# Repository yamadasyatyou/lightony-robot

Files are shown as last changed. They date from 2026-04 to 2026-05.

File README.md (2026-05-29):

# LIGHTONY ROBOT
lightony_robot_readme

A Spresense-based lamp robot with voice recognition.

---

## Overview
LIGHTONY is an interactive lamp robot powered by the Sony Spresense platform. It features voice recognition capabilities, allowing it to respond to voice commands and express emotions through light and movement.

🏆 **Winner of the Grand Prize (Entertainment Category) at [the SPRESENSE Application Contest 2025](https://elchika.com/promotion/spresense2025/winner/#nav)**

🎥 **Watch the demo video:** [Click here to watch on YouTube](https://youtube.com/shorts/HmzlsDdo05Y?si=zyfIlw46z9iSeXyk)

## Features
* **Voice Recognition:** Understands and reacts to specific voice commands.
* **Interactive Lighting:** Expresses different states and emotions using LEDs.
* **Spresense Powered:** Utilizes the high-performance computing of the Sony Spresense board.

## Directory Structure
```text
lightony-robot/
 ├── hardware/      # Mechanical and PCB design files (with schematics)
 ├── software/      # Source code for Sony Spresense
 └── README.md
```
## Acknowledgments
The edge AI implementation and Spresense control in this project were greatly inspired by and developed with reference to the following book and its accompanying repository:

* **Book:** *[SPRESENSEではじめるローパワーエッジAI](https://www.oreilly.co.jp/books/9784873119670/)* (Low-Power Edge AI with SPRESENSE) by Yoshinori Oota
* **Repository:** [TE-YoshinoriOota/Spresense-LowPower-EdgeAI](https://github.com/TE-YoshinoriOota/Spresense-LowPower-EdgeAI)

## License
This project is dual-licensed to protect both the software and the hardware designs:

* **Software (Source Code):** Licensed under the [GNU Lesser General Public License v2.1 (LGPL-2.1)](LICENSE).
* **Hardware & 3D Models:** Licensed under the [Creative Commons Attribution-NonCommercial 4.0 International (CC BY-NC 4.0)](https://creativecommons.org/licenses/by-nc/4.0/). 
  *(Non-commercial use only. Selling the physical robot or parts is strictly prohibited.)*

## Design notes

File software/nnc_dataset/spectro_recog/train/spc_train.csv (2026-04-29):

x:scp | y:label
./wake_up/000.bmp | 0
./wake_up/001.bmp | 0
./wake_up/002.bmp | 0
./wake_up/003.bmp | 0
./wake_up/004.bmp | 0
./wake_up/005.bmp | 0
./wake_up/006.bmp | 0
./wake_up/007.bmp | 0
./wake_up/008.bmp | 0
./wake_up/009.bmp | 0
./wake_up/010.bmp | 0
./wake_up/011.bmp | 0
./wake_up/012.bmp | 0
./wake_up/013.bmp | 0
./wake_up/014.bmp | 0
./wake_up/015.bmp | 0
./wake_up/016.bmp | 0
./wake_up/017.bmp | 0
./wake_up/018.bmp | 0
./wake_up/019.bmp | 0
./wake_up/020.bmp | 0
./wake_up/021.bmp | 0
./wake_up/022.bmp | 0
./wake_up/023.bmp | 0
./wake_up/024.bmp | 0
./wake_up/025.bmp | 0
./wake_up/026.bmp | 0
./wake_up/027.bmp | 0
./wake_up/028.bmp | 0
./wake_up/029.bmp | 0
./wake_up/030.bmp | 0
./wake_up/031.bmp | 0
./wake_up/032.bmp | 0
./wake_up/033.bmp | 0
./wake_up/034.bmp | 0
./wake_up/035.bmp | 0
./wake_up/036.bmp | 0
./wake_up/037.bmp | 0
./wake_up/038.bmp | 0
./wake_up/039.bmp | 0
./wake_up/040.bmp | 0
./wake_up/041.bmp | 0
./wake_up/042.bmp | 0
./wake_up/043.bmp | 0
./wake_up/044.bmp | 0
./wake_up/045.bmp | 0
./wake_up/046.bmp | 0
./wake_up/047.bmp | 0
./wake_up/048.bmp | 0
./wake_up/049.bmp | 0
./good_night/000.bmp | 1
./good_night/001.bmp | 1
./good_night/002.bmp | 1
./good_night/003.bmp | 1
./good_night/004.bmp | 1
./good_night/005.bmp | 1
./good_night/006.bmp | 1
./good_night/007.bmp | 1
./good_night/008.bmp | 1
./good_night/009.bmp | 1
./good_night/010.bmp | 1
./good_night/011.bmp | 1
./good_night/012.bmp | 1
./good_night/013.bmp | 1
./good_night/014.bmp | 1
./good_night/015.bmp | 1
./good_night/016.bmp | 1
./good_night/017.bmp | 1
./good_night/018.bmp | 1
./good_night/019.bmp | 1
./good_night/020.bmp | 1
./good_night/021.bmp | 1
./good_night/022.bmp | 1
./good_night/023.bmp | 1
./good_night/024.bmp | 1
./good_night/025.bmp | 1
./good_night/026.bmp | 1
./good_night/027.bmp | 1
./good_night/028.bmp | 1
./good_night/029.bmp | 1
./good_night/030.bmp | 1
./good_night/031.bmp | 1
./good_night/032.bmp | 1
./good_night/033.bmp | 1
./good_night/034.bmp | 1
./good_night/035.bmp | 1
./good_night/036.bmp | 1
./good_night/037.bmp | 1
./good_night/038.bmp | 1
./good_night/039.bmp | 1
./good_night/040.bmp | 1
./good_night/041.bmp | 1
./good_night/042.bmp | 1
./good_night/043.bmp | 1
./good_night/044.bmp | 1
./good_night/045.bmp | 1
./good_night/046.bmp | 1
./good_night/047.bmp | 1
./good_night/048.bmp | 1
./good_night/049.bmp | 1
./brightly/000.bmp | 2
./brightly/001.bmp | 2
./brightly/002.bmp | 2
./brightly/003.bmp | 2
./brightly/004.bmp | 2
./brightly/005.bmp | 2
./brightly/006.bmp | 2
./brightly/007.bmp | 2
./brightly/008.bmp | 2
./brightly/009.bmp | 2
./brightly/010.bmp | 2
./brightly/011.bmp | 2
./brightly/012.bmp | 2
./brightly/013.bmp | 2
./brightly/014.bmp | 2
./brightly/015.bmp | 2
./brightly/016.bmp | 2
./brightly/017.bmp | 2
./brightly/018.bmp | 2
./brightly/019.bmp | 2
./brightly/020.bmp | 2
./brightly/021.bmp | 2
./brightly/022.bmp | 2
./brightly/023.bmp | 2
./brightly/024.bmp | 2
./brightly/025.bmp | 2
./brightly/026.bmp | 2
./brightly/027.bmp | 2
./brightly/028.bmp | 2
./brightly/029.bmp | 2
./brightly/030.bmp | 2
./brightly/031.bmp | 2
./brightly/032.bmp | 2
./brightly/033.bmp | 2
./brightly/034.bmp | 2
./brightly/035.bmp | 2
./brightly/036.bmp | 2
./brightly/037.bmp | 2
./brightly/038.bmp | 2
./brightly/039.bmp | 2
./brightly/040.bmp | 2
./brightly/041.bmp | 2
./brightly/042.bmp | 2
./brightly/043.bmp | 2
./brightly/044.bmp | 2
./brightly/045.bmp | 2
./brightly/046.bmp | 2
./brightly/047.bmp | 2
./brightly/048.bmp | 2
./brightly/049.bmp | 2
./darkly/000.bmp | 3
./darkly/001.bmp | 3
./darkly/002.bmp | 3
./darkly/003.bmp | 3
./darkly/004.bmp | 3
./darkly/005.bmp | 3
./darkly/006.bmp | 3
./darkly/007.bmp | 3
./darkly/008.bmp | 3
./darkly/009.bmp | 3
./darkly/010.bmp | 3
./darkly/011.bmp | 3
./darkly/012.bmp | 3
./darkly/013.bmp | 3
./darkly/014.bmp | 3
./darkly/015.bmp | 3
./darkly/016.bmp | 3
./darkly/017.bmp | 3
./darkly/018.bmp | 3
./darkly/019.bmp | 3
./darkly/020.bmp | 3
./darkly/021.bmp | 3
./darkly/022.bmp | 3
./darkly/023.bmp | 3
./darkly/024.bmp | 3
./darkly/025.bmp | 3
./darkly/026.bmp | 3
./darkly/027.bmp | 3
./darkly/028.bmp | 3
./darkly/029.bmp | 3
./darkly/030.bmp | 3
./darkly/031.bmp | 3
./darkly/032.bmp | 3
./darkly/033.bmp | 3
./darkly/034.bmp | 3
./darkly/035.bmp | 3
./darkly/036.bmp | 3
./darkly/037.bmp | 3
./darkly/038.bmp | 3
./darkly/039.bmp | 3
./darkly/040.bmp | 3
./darkly/041.bmp | 3
./darkly/042.bmp | 3
./darkly/043.bmp | 3
./darkly/044.bmp | 3
./darkly/045.bmp | 3
./darkly/046.bmp | 3
./darkly/047.bmp | 3
./darkly/048.bmp | 3
./darkly/049.bmp | 3
./clap/000.bmp | 4
./clap/001.bmp | 4
./clap/002.bmp | 4
./clap/003.bmp | 4
./clap/004.bmp | 4
./clap/005.bmp | 4
./clap/006.bmp | 4
./clap/007.bmp | 4
./clap/008.bmp | 4
./clap/009.bmp | 4
./clap/010.bmp | 4
./clap/011.bmp | 4
./clap/012.bmp | 4
./clap/013.bmp | 4
./clap/014.bmp | 4
./clap/015.bmp | 4
./clap/016.bmp | 4
./clap/017.bmp | 4
./clap/018.bmp | 4
./clap/019.bmp | 4
./clap/020.bmp | 4
./clap/021.bmp | 4
./clap/022.bmp | 4
./clap/023.bmp | 4
./clap/024.bmp | 4
./clap/025.bmp | 4
./clap/026.bmp | 4
./clap/027.bmp | 4
./clap/028.bmp | 4
./clap/029.bmp | 4
./clap/030.bmp | 4
./clap/031.bmp | 4
./clap/032.bmp | 4
./clap/033.bmp | 4
./clap/034.bmp | 4
./clap/035.bmp | 4
./clap/036.bmp | 4
./clap/037.bmp | 4
./clap/038.bmp | 4
./clap/039.bmp | 4
./clap/040.bmp | 4
./clap/041.bmp | 4
./clap/042.bmp | 4
./clap/043.bmp | 4
./clap/044.bmp | 4
./clap/045.bmp | 4
./clap/046.bmp | 4
./clap/047.bmp | 4
./clap/048.bmp | 4
./clap/049.bmp | 4
./blow/000.bmp | 5
./blow/001.bmp | 5
./blow/002.bmp | 5
./blow/003.bmp | 5
./blow/004.bmp | 5
./blow/005.bmp | 5
./blow/006.bmp | 5
./blow/007.bmp | 5
./blow/008.bmp | 5
./blow/009.bmp | 5
./blow/010.bmp | 5
./blow/011.bmp | 5
./blow/012.bmp | 5
./blow/013.bmp | 5
./blow/014.bmp | 5
./blow/015.bmp | 5
./blow/016.bmp | 5
./blow/017.bmp | 5
./blow/018.bmp | 5
./blow/019.bmp | 5
./blow/020.bmp | 5
./blow/021.bmp | 5
./blow/022.bmp | 5
./blow/023.bmp | 5
./blow/024.bmp | 5
./blow/025.bmp | 5
./blow/026.bmp | 5
./blow/027.bmp | 5
./blow/028.bmp | 5
./blow/029.bmp | 5
./blow/030.bmp | 5
./blow/031.bmp | 5
./blow/032.bmp | 5
./blow/033.bmp | 5
./blow/034.bmp | 5
./blow/035.bmp | 5
./blow/036.bmp | 5
./blow/037.bmp | 5
./blow/038.bmp | 5
./blow/039.bmp | 5
./blow/040.bmp | 5
./blow/041.bmp | 5
./blow/042.bmp | 5
./blow/043.bmp | 5
./blow/044.bmp | 5
./blow/045.bmp | 5
./blow/046.bmp | 5
./blow/047.bmp | 5
./blow/048.bmp | 5
./blow/049.bmp | 5

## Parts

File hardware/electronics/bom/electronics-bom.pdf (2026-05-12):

Qty | Name | Model | Remarks | Vendor
1 | SPRESENSE Main Board | CXD5602PWBMAIN1 | | Sony Semiconductor Solutions
1 | SPRESENSE Extension Board | CXD5602PWBEXT1 | | Sony Semiconductor Solutions
2 | Electret condenser microphone | ECM-SP10 | | SONY
1 | Filament LED bulb | ST58-6W-E27-WW | | 12Vmonster
1 | E26 Lamp socket with cord | HS-L2615ZR/W | Original cord cut, terminated with 2-pin PH connector (L = 50mm AWG24) | OHM ELECTRIC
1 | Cable assembly | 5-Pin PH to PH (L = 200mm AWG24 Straight) | Control board to Power supply board | J.S.T. MFG
1 | microSD card | 16GB class10
2 | Servo motor | RS304MD | Eyelid & Neck Yaw Drive | Futaba
1 | Servo motor | RS303MR | Neck Pitch Drive | Futaba
1 | Custom PCB | control board | FR-4, 0.8mm thick, black solder mask
1 | Custom PCB | power supply board | FR-4, 0.8mm thick, black solder mask

electronics BOM

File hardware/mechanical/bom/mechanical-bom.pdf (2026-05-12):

Qty | Name | Model | Remarks | Vendor
2 | 3D printed parts | arm-frame-lower.stl
2 | 3D printed parts | arm-frame-upper.stl
1 | 3D printed parts | arm-hand-left.stl | Print in white
1 | 3D printed parts | arm-hand-right.stl | Print in white
2 | 3D printed parts | arm-wrist-bracket.stl | Print in white
1 | 3D printed parts | body-battery-cover-mount.stl | Print in black
1 | 3D printed parts | body-frame-lower.stl
1 | 3D printed parts | body-frame-upper.stl
1 | 3D printed parts | head-eye-base.stl | Print in white
2 | 3D printed parts | head-eyebrow.stl | Print in black
1 | 3D printed parts | head-eyelid-gear.stl
1 | 3D printed parts | head-eyelid-servo-mount-a.stl
1 | 3D printed parts | head-eyelid-servo-mount-b.stl
1 | 3D printed parts | head-eyelid.stl | Print in beige or similar
1 | 3D printed parts | head-frame-left.stl
1 | 3D printed parts | head-frame-right.stl
1 | 3D printed parts | head-nose.stl | Print in beige or similar
2 | 3D printed parts | head-pupil.stl | Print in black
1 | 3D printed parts | head-socket-mount.stl
4 | 3D printed parts | leg-frame.stl
1 | 3D printed parts | neck-main.stl | Print in beige or similar
1 | 3D printed parts | neck-pitch-bracket-a.stl
1 | 3D printed parts | neck-pitch-bracket-b.stl
1 | 3D printed parts | neck-pitch-servo-mount-a.stl
1 | 3D printed parts | neck-pitch-servo-mount-b.stl
1 | 3D printed parts | neck-yaw-bracket.stl
1 | 3D printed parts | neck-yaw-servo-mount.stl
2 | 3D printed parts | neck-yaw-support.stl
2 | Laser cut parts (2mm shina plywood) | arm-panel-lower-a.dxf
2 | Laser cut parts (2mm shina plywood) | arm-panel-lower-b.dxf
1 | Laser cut parts (2mm shina plywood) | arm-panel-lower-c.dxf
2 | Laser cut parts (2mm shina plywood) | arm-panel-upper-a.dxf
1 | Laser cut parts (2mm shina plywood) | arm-panel-upper-b.dxf
1 | Laser cut parts (2mm shina plywood) | arm-panel-upper-c.dxf

mechanical BOM

1 | Laser cut parts (2mm shina plywood) | arm-panel-upper-d.dxf 1 | Laser cut parts (2mm shina plywood) | arm-panel-upper-e.dxf 1 | Laser cut parts (2mm shina plywood) | body-battery-cover.dxf 1 | Laser cut parts (2mm shina plywood) | body-panel-bottom.dxf 1 | Laser cut parts (2mm shina plywood) | body-panel-front.dxf 1 | Laser cut parts (2mm shina plywood) | body-panel-left.dxf 1 | Laser cut parts (2mm shina plywood) | body-panel-rear.dxf 1 | Laser cut parts (2mm shina plywood) | body-panel-right.dxf 1 | Laser cut parts (2mm shina plywood) | body-panel-top.dxf 1 | Laser cut parts (2mm shina plywood) | head-panel-bottom.dxf 1 | Laser cut parts (2mm shina plywood) | head-panel-front.dxf 1 | Laser cut parts (2mm shina plywood) | head-panel-left.dxf 1 | Laser cut parts (2mm shina plywood) | head-panel-rear.dxf 1 | Laser cut parts (2mm shina plywood) | head-panel-right.dxf 1 | Laser cut parts (2mm shina plywood) | head-panel-top.dxf 2 | Laser cut parts (2mm shina plywood) | foot-panel.dxf 8 | Laser cut parts (2mm shina plywood) | leg-panel.dxf
88 | Pan head tapping screw (B-tite) | M2x5 2 | Pan head tapping screw (B-tite) | M2x10 2 | Pan head tapping screw (B-tite) | M2x15 6 | Pan head screw | M2x8 4 | Spacer | M2x2 4 | Hex nut | M2 1 | Hex standoff | M2x10 2 | Pan head tapping screw (B-tite) | M3x16 2 | Pan head tapping screw (B-tite) | M3x30 4 | Pan head screw | M3x35 4 | Countersunk screw | M3x50 2 | Spacer | M3x2 2 | Spacer | M3x3 2 | Spacer | M3x5 4 | Spacer | M3x10 8 | Spacer | M3x22 4 | Hex nut | M3 2 | Pan head tapping screw (B-tite) | M5x25 4 | Flanged ball bearing | DDLF-730ZZ | MinebeaMitsumi

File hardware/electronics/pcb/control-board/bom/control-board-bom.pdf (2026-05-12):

Qty | Ref | Name | Model | Vendor
2 | C1, C12 | Ceramic capacitor 4.7uF (25V X5R 2012)
6 | C10, C11, C19, C20, C21, C22 | Ceramic capacitor 0.1uF (50V X7R 1608)
2 | C2, C13 | Ceramic capacitor 330pF (50V C0G 1608)
4 | C3, C4, C9, C14 | Ceramic capacitor 10uF (16V X5R 2012)
8 | C5, C6, C7, C8, C15, C16, C17, C18 | Ceramic capacitor 47uF (16V X5R 1210)
2 | R1, R2 | Chip resistor 2.2kΩ (1/10W 1608 1%)
1 | R13 | Chip resistor 1MΩ (1/10W 1608 1%)
1 | R14 | Chip resistor 47kΩ (1/10W 1608 1%)
3 | R16, R17, R18 | DNP
1 | R19 | Chip resistor 280kΩ (1/10W 1608 1%)
1 | R20 | Chip resistor 274kΩ (1/10W 1608 1%)
1 | R21 | Chip resistor 267kΩ (1/10W 1608 1%)
1 | R22 | Chip resistor 255kΩ (1/10W 1608 1%)
1 | R23 | Chip resistor 1kΩ (1/10W 1608 1%)
2 | R3, R9 | Chip resistor 76.8kΩ (1/10W 1608 1%)
2 | R4, R10 | Chip resistor 127kΩ (1/10W 1608 1%)
3 | R5, R11, R15 | Chip resistor 0Ω (1608)
2 | R6, R12 | Chip resistor 100kΩ (1/10W 1608 1%)
1 | R7 | Chip resistor 536kΩ (1/10W 1608 1%)
1 | R8 | Chip resistor 102kΩ (1/10W 1608 1%)
2 | L1, L2 | Power inductor 4.7uH | 0630CDMCCDS-4R7MC | Sumida
1 | CN1 | Wire-to-Board connector 5P | B5B-PH-SM4-TB | J.S.T. MFG
1 | CN2 | Wire-to-Board connector 2P | B2B-PH-SM4-TB | J.S.T. MFG
2 | MICA, MICB | Headphone jack | SJ2-3574A-SMT-TR | Same Sky
2 | JP1, JP3 | Pin header (2.54mm pitch/8P) | M20-9730845 | Harwin
1 | JP2 | Pin header (2.54mm pitch/6P) | M20-9770646 | Harwin
1 | JP4 | Pin header (2.54mm pitch/10P) | M20-7830842 | Harwin
1 | JP5 | Pin Socket (2.54mm pitch/2line/16P) | M20-7830842 | Harwin
1 | JP6 | Pin header (2.54mm pitch/2line/6P) | M20-8760342 | Harwin
2 | U1, U2 | Buck-Boost DC/DC converter | LTC3119EFE#PBF | Analog Devices
2 | U3, U4 | Quad analog switch | NJU211 | Nisshinbo Micro Devices
1 | U5 | Digital transistor (NPN) | DTC114EKA146 | Rohm

control board BOM

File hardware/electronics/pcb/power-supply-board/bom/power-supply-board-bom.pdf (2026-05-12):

Qty | Ref | Name | Model | Vendor 3 | C1, C2, C3 | Ceramic capacitor 10uF (16V X5R 2012) 1 | CN1 | Wire-to-Board connector 5P | S5B-PH-SM4-TB | J.S.T. MFG 1 | JP1 | Pin header (2.54mm pitch/2line/6P) | M20-8760342 | Harwin 1 | SW1 | Slide switch (SPST) | L101011ML04Q | C&K 1 | BAT1 | Battery box (AA x 4) | SN3-4PC | TAKACHI

### power supply board BOM

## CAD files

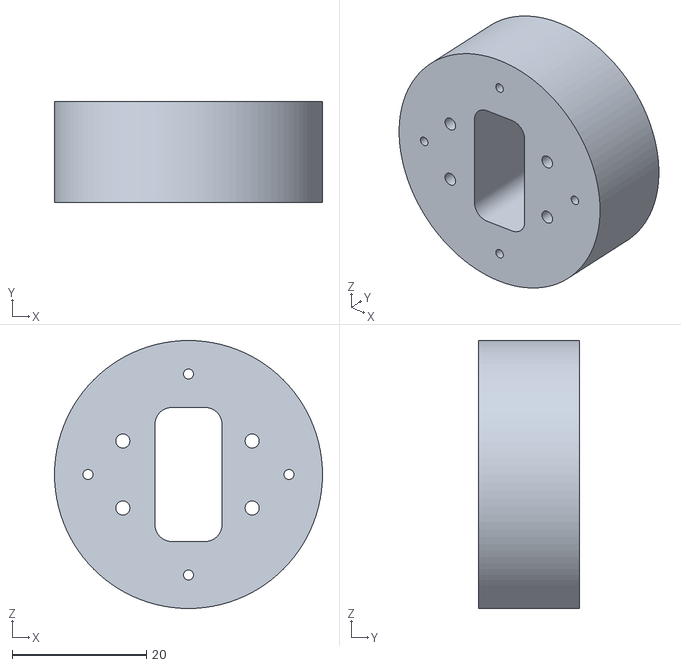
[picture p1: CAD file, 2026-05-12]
hardware/mechanical/3d-printed-parts/neck/neck-main.stl
40.0 x 15.0 x 40.0

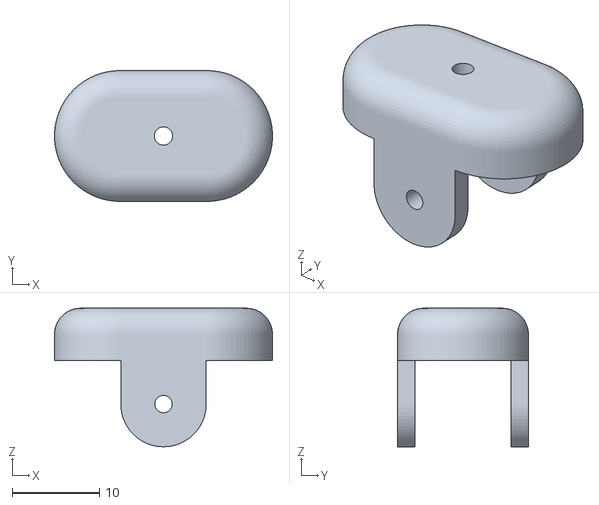
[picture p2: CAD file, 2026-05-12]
hardware/mechanical/3d-printed-parts/arm/arm-wrist-bracket.stl
25.0 x 15.0 x 15.9

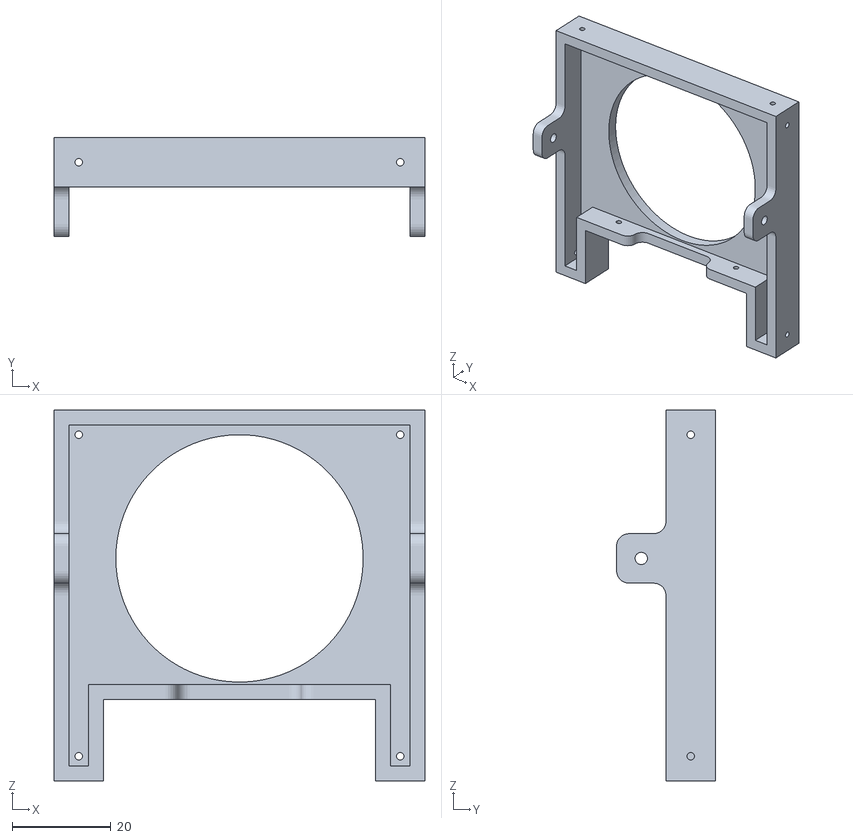
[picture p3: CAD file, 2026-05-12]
hardware/mechanical/3d-printed-parts/body/body-frame-upper.stl
75.0 x 20.0 x 75.0

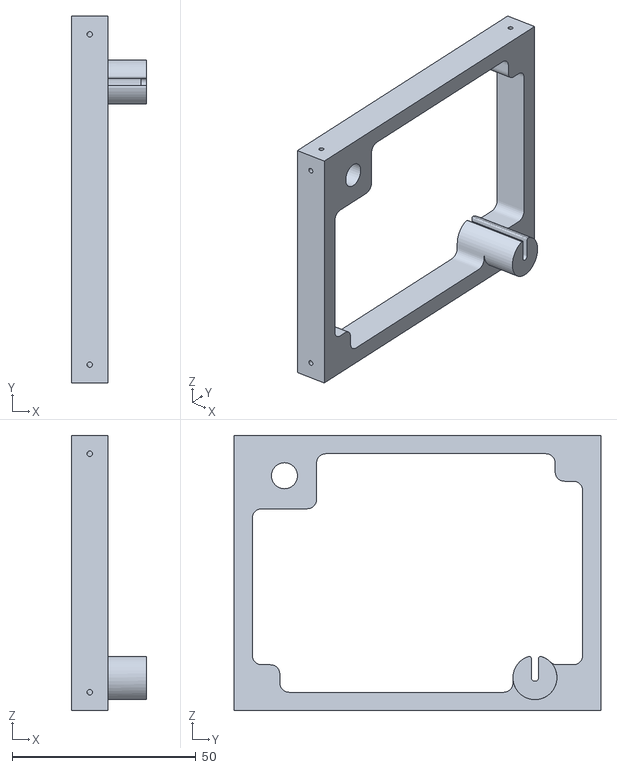
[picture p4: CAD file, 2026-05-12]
hardware/mechanical/3d-printed-parts/head/head-frame-right.stl
20.5 x 100.0 x 75.0

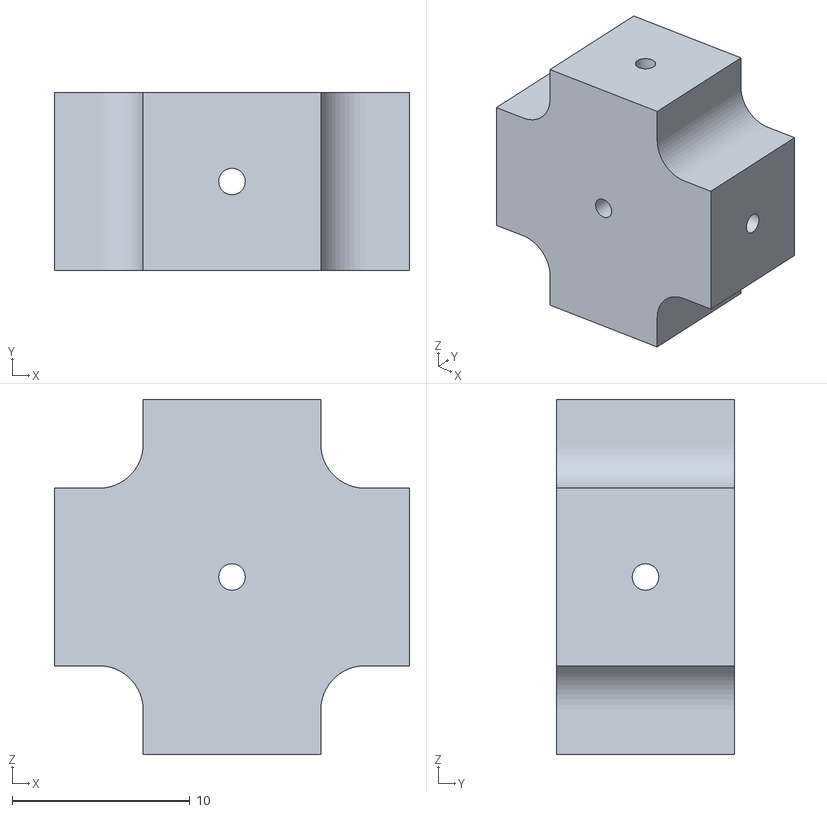
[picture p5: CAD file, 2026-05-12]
hardware/mechanical/3d-printed-parts/legs/leg-frame.stl
20.0 x 10.0 x 20.0

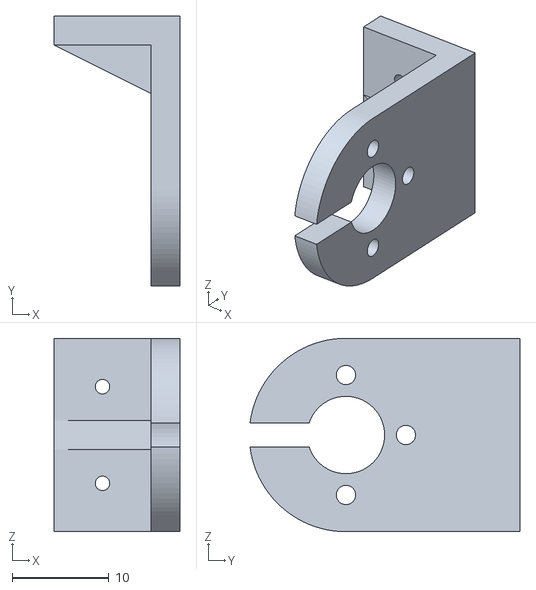
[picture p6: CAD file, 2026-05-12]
hardware/mechanical/3d-printed-parts/neck/neck-pitch-bracket-b.stl
13.0 x 27.9 x 20.0

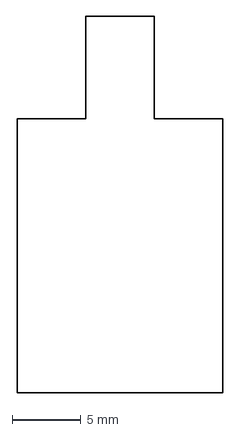
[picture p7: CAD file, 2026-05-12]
hardware/mechanical/laser-cut-parts/arm/arm-panel-lower-a.dxf
15.0 x 27.5 mm

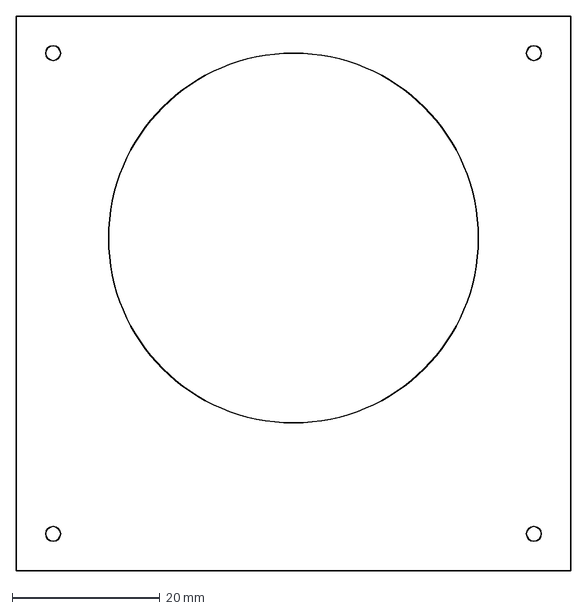
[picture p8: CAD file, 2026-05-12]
hardware/mechanical/laser-cut-parts/body/body-panel-top.dxf
75.0 x 75.0 mm

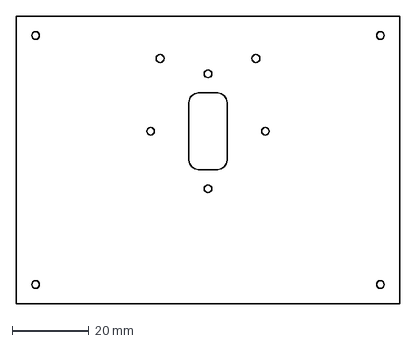
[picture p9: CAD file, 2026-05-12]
hardware/mechanical/laser-cut-parts/head/head-panel-bottom.dxf
100.0 x 75.0 mm

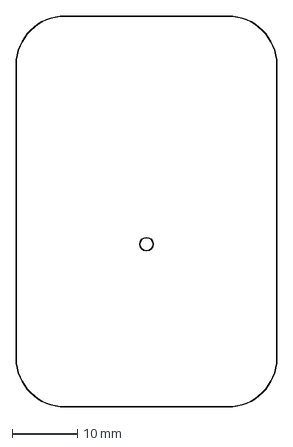
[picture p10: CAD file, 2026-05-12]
hardware/mechanical/laser-cut-parts/legs/foot-panel.dxf
40.0 x 60.0 mm

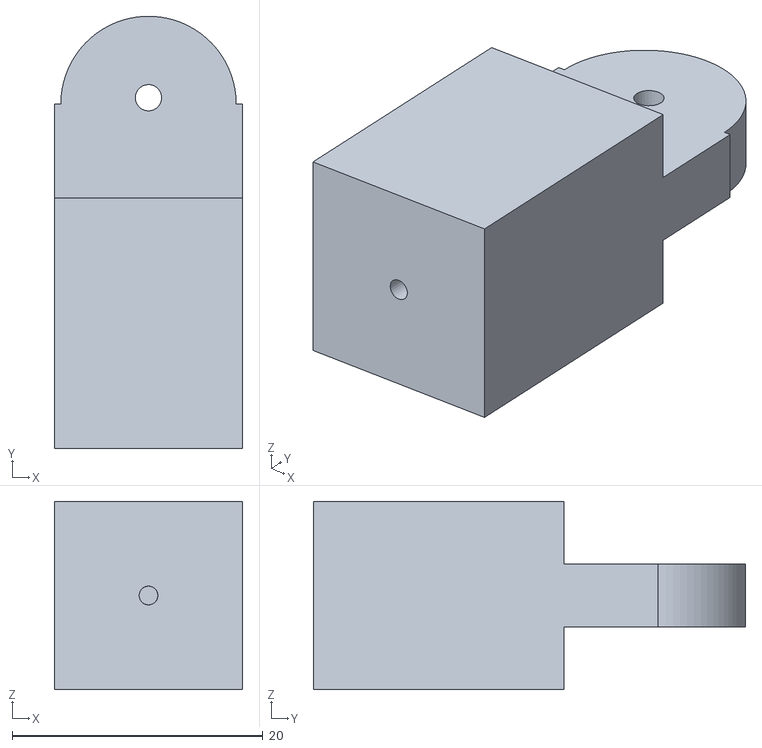
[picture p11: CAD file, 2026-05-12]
hardware/mechanical/3d-printed-parts/arm/arm-frame-lower.stl
15.0 x 34.5 x 15.0

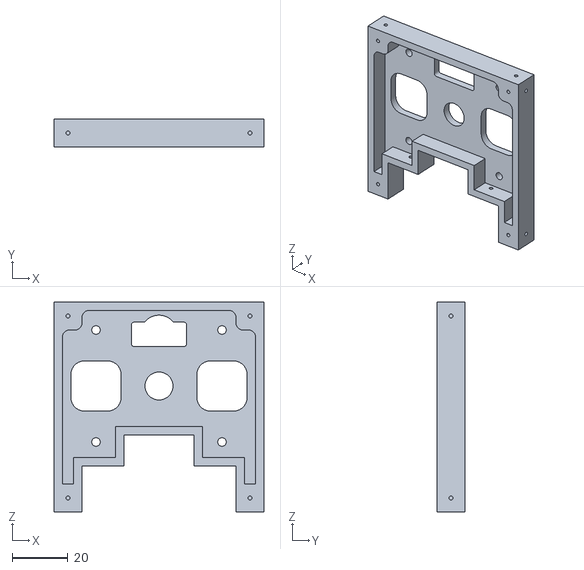
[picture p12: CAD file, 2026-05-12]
hardware/mechanical/3d-printed-parts/body/body-frame-lower.stl
75.0 x 10.0 x 75.0

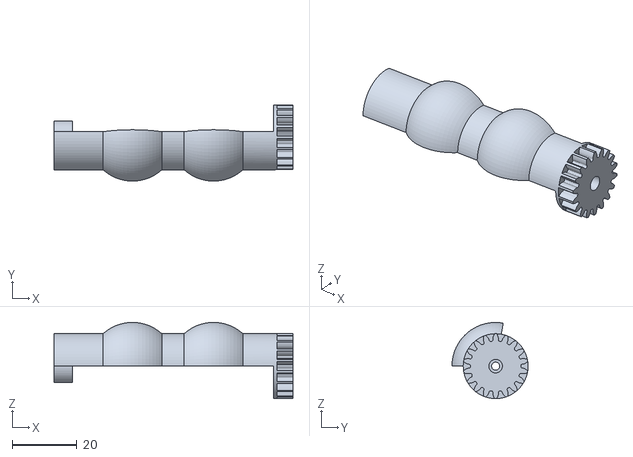
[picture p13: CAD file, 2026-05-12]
hardware/mechanical/3d-printed-parts/head/head-eyelid.stl
73.7 x 23.5 x 23.5

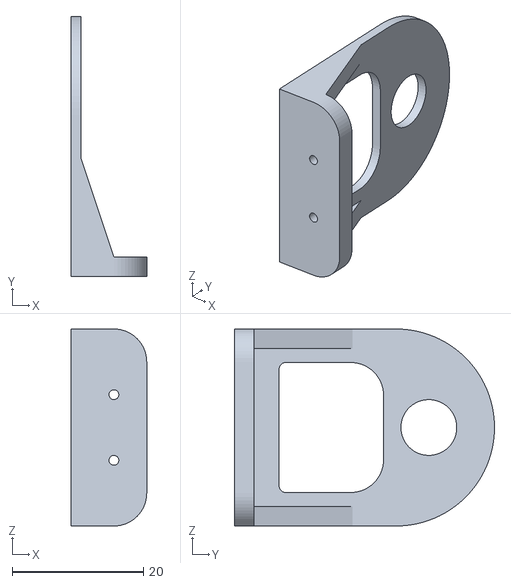
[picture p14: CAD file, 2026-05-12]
hardware/mechanical/3d-printed-parts/neck/neck-pitch-servo-mount-a.stl
11.5 x 39.6 x 30.0

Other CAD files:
hardware/mechanical/laser-cut-parts/arm/arm-panel-upper-e.dxf
hardware/mechanical/laser-cut-parts/body/body-panel-bottom.dxf
hardware/mechanical/laser-cut-parts/head/head-panel-rear.dxf
hardware/mechanical/laser-cut-parts/legs/leg-panel.dxf
hardware/mechanical/3d-printed-parts/arm/arm-frame-upper.stl
hardware/mechanical/3d-printed-parts/arm/arm-hand-left.stl
hardware/mechanical/3d-printed-parts/arm/arm-hand-right.stl
hardware/mechanical/3d-printed-parts/body/body-battery-cover-mount.stl
hardware/mechanical/3d-printed-parts/head/head-eye-base.stl
hardware/mechanical/3d-printed-parts/head/head-eyebrow.stl
hardware/mechanical/3d-printed-parts/head/head-eyelid-gear.stl
hardware/mechanical/3d-printed-parts/head/head-eyelid-servo-mount-a.stl
hardware/mechanical/3d-printed-parts/head/head-eyelid-servo-mount-b.stl
hardware/mechanical/3d-printed-parts/head/head-frame-left.stl
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

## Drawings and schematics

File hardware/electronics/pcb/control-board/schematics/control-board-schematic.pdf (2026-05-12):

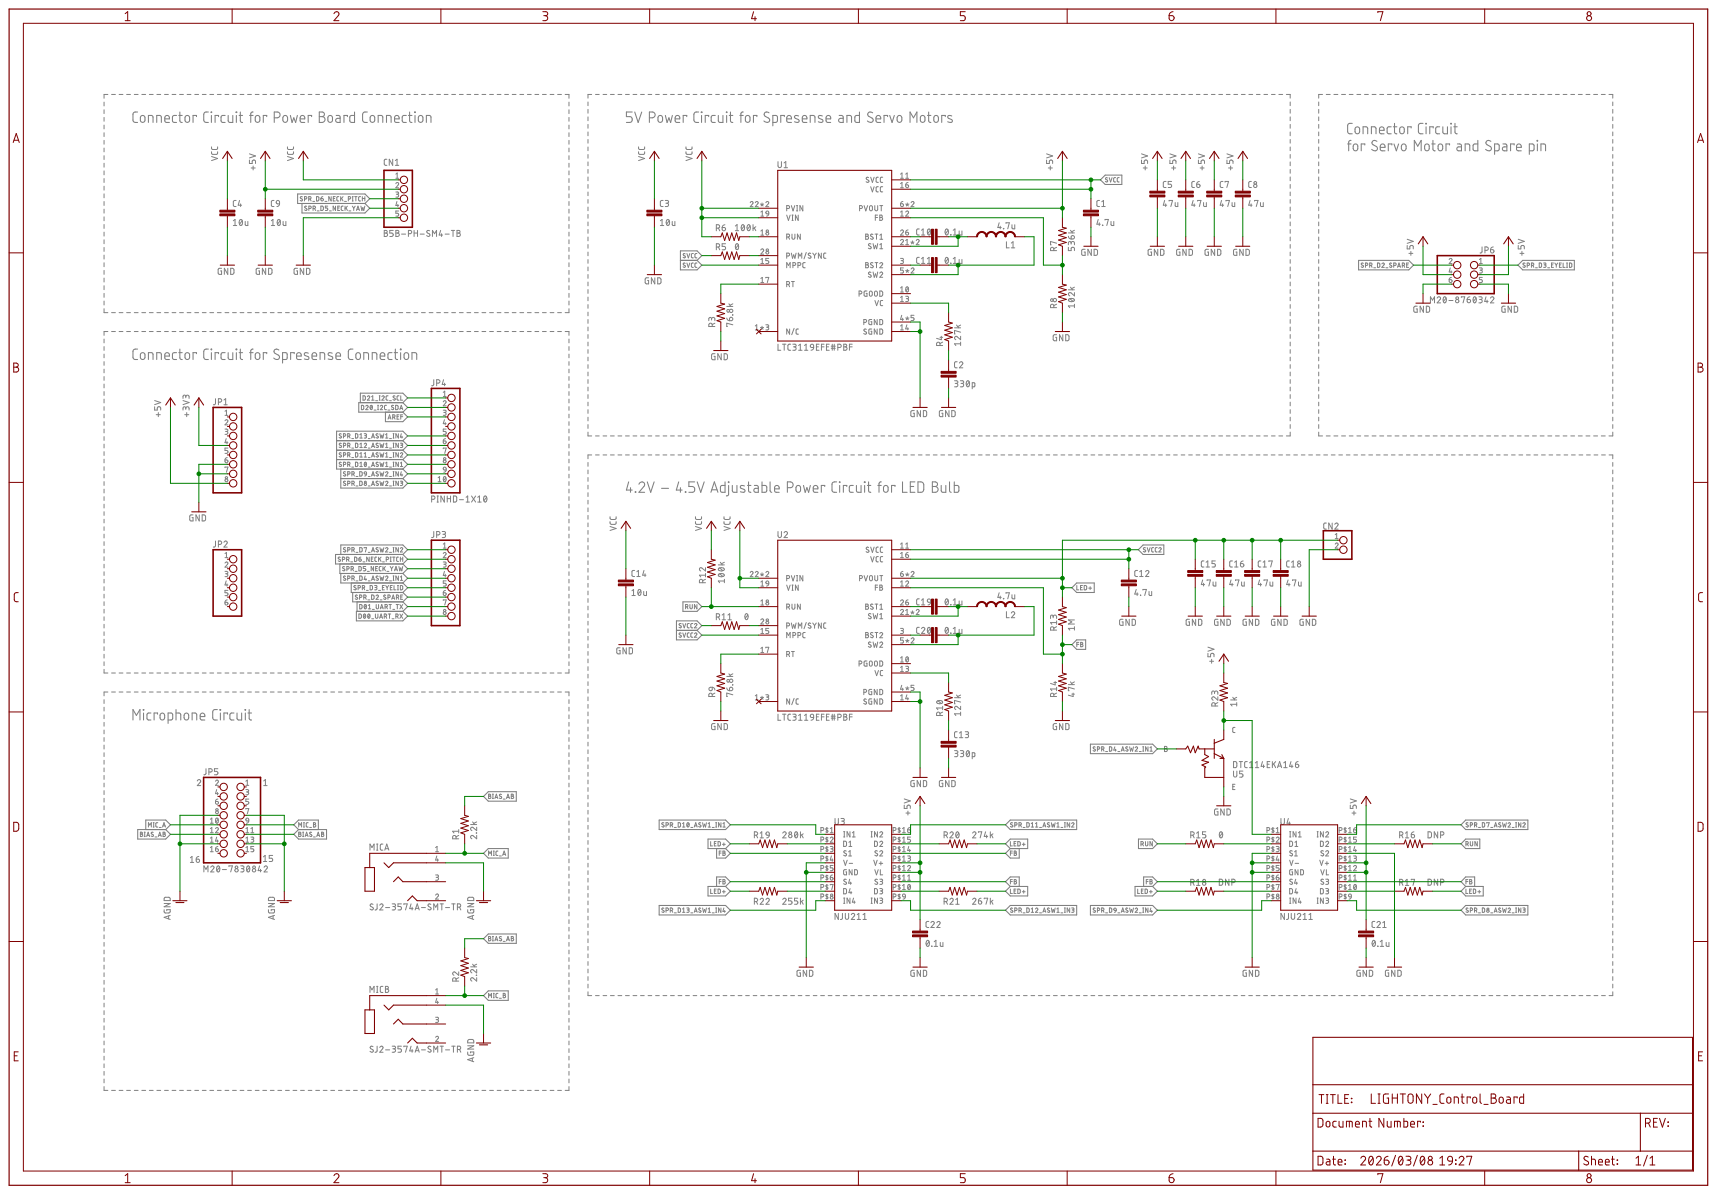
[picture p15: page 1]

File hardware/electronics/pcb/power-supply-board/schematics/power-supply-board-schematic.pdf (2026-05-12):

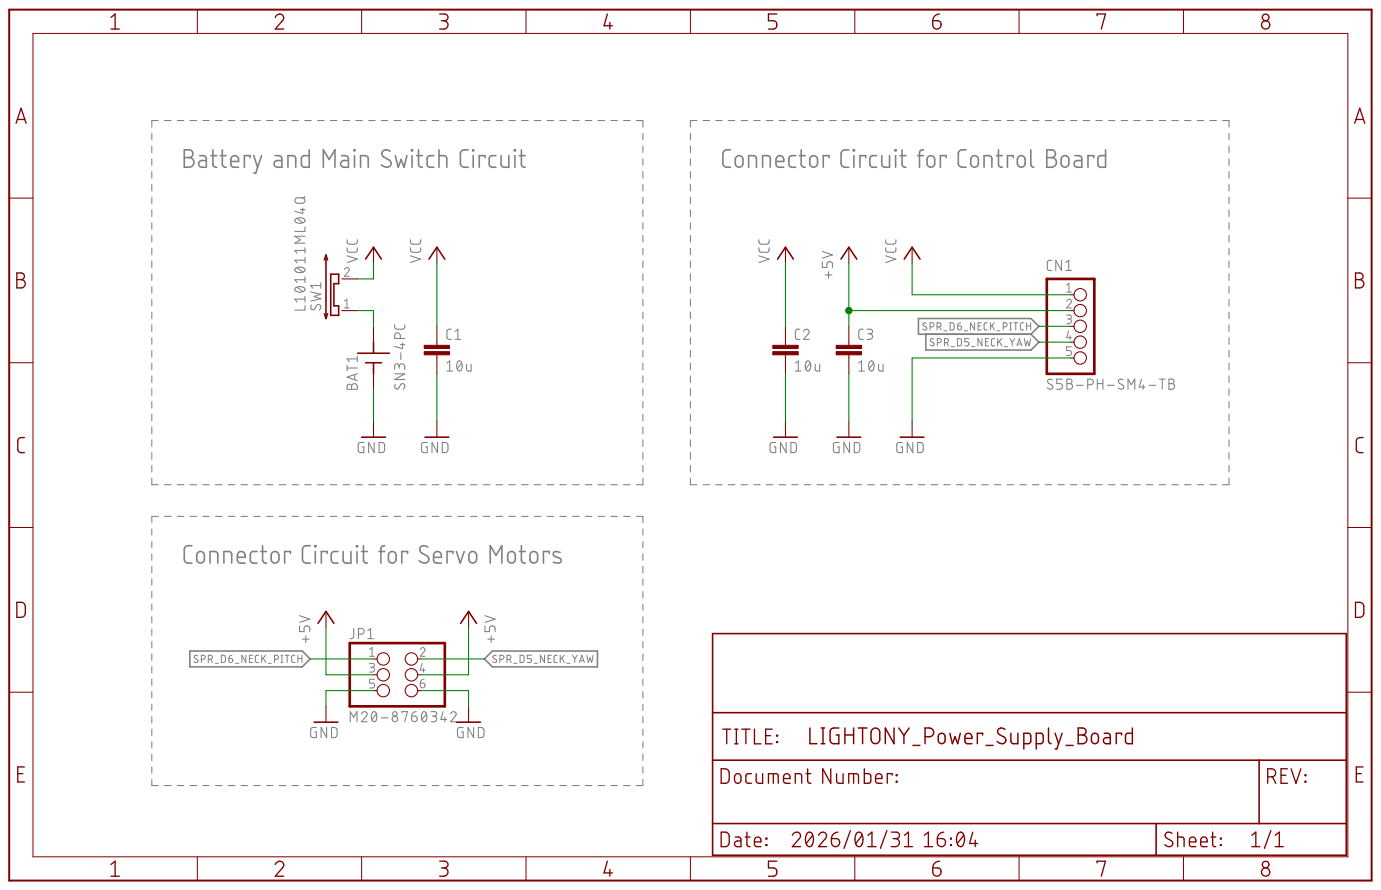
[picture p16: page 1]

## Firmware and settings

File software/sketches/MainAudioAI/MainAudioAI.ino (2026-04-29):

/**
 * LIGHTONY ROBOT - Main Audio AI Control
 * * This sketch implements the core voice recognition and lamp control logic 
 * for the LIGHTONY robot.
 * * Acknowledgments:
 * This code is developed with reference to the "MainAudioAI.ino" sample from:
 * - Book: "SPRESENSEではじめるローパワーエッジAI" by Yoshinori Oota
 * - Repository: https://github.com/TE-YoshinoriOota/Spresense-LowPower-EdgeAI
 * * The original logic for Spresense-based Edge AI inference has been 
 * adapted and integrated into the LIGHTONY project.
 */

#ifdef SUBCORE
#error "Core selection is wrong!!"
#endif

#include <Audio.h>
#include <FFT.h>
#include <SDHCI.h>
#include <float.h>
#include <DNNRT.h>
#include <Servo.h>

// -----------------------------------------------------------------------------
// Compile-time constants and global library objects
// -----------------------------------------------------------------------------
#define FFT_LEN 512
#define NNB_FILE "model.nnb"
#define BUFFERING_TIME_MS (FFT_LEN * 1000 / AS_SAMPLINGRATE_16000)
#define BUFFER_SIZE_BYTES (FFT_LEN * sizeof(int16_t) * AS_CHANNEL_STEREO)

FFTClass<AS_CHANNEL_STEREO, FFT_LEN> FFT;
AudioClass* theAudio = AudioClass::getInstance();
SDClass SD;
DNNRT dnnrt;

// =========================
// Types: Step, Sequence
// =========================
enum Level : int8_t {
  LEVEL_KEEP = -1,
  LEVEL_OFF  = 0,
  LEVEL_LOW,
  LEVEL_MID,
  LEVEL_HIGH,
  LEVEL_FULL
};

struct Step {
  int eyelidDeg;
  int pitchDeg;
  int yawDeg;
  uint16_t stepDelayMs;
  uint16_t holdMs;
  Level level;
};

struct Sequence {
  const Step* steps;
  int count;
};

// =========================
// SmoothServo
// =========================
struct SmoothServo {
  Servo s;
  int cur, target;
  uint16_t stepMs;
  unsigned long lastMs;
  SmoothServo(int initAngle = 90) : cur(initAngle), target(initAngle), stepMs(10), lastMs(0) {}
  void attach(int pin) { s.attach(pin); s.write(cur); }
  void setTarget(int t, uint16_t ms) { target = constrain(t, 0, 180); stepMs = (ms == 0) ? 1 : ms; }
  void update(unsigned long now) {
    if (cur == target) return;
    if ((now - lastMs) >= stepMs) {
      lastMs = now;
      int stepSize = 1;
      if (stepMs <= 1) stepSize = 12;
      else if (stepMs <= 3) stepSize = 8;
      else if (stepMs <= 8) stepSize = 4;
      else if (stepMs <= 20) stepSize = 2;
      int diff = target - cur;
      if (diff > 0) cur += min(stepSize, diff);
      else cur -= min(stepSize, -diff);
      cur = constrain(cur, 0, 180);
      s.write(cur);
    }
  }
  bool moving() const { return cur != target; }
};

// サーボ初期角度
SmoothServo Eyelid(112), Pitch(97), Yaw(95);

// =========================
// Level pins / table
// =========================
static const uint8_t kLevelPins[] = {4, 10, 11, 12, 13};
static const int kLevelPinCount = (int)(sizeof(kLevelPins) / sizeof(kLevelPins[0]));

struct LevelPattern { Level level; uint8_t pinState[5]; };
static const LevelPattern kLevelTable[] = {
  { LEVEL_FULL, {LOW, LOW,  HIGH, HIGH, HIGH} },
  { LEVEL_HIGH, {LOW, HIGH, LOW,  HIGH, HIGH} },
  { LEVEL_MID,  {LOW, HIGH, HIGH, LOW,  HIGH} },
  { LEVEL_LOW,  {LOW, HIGH, HIGH, HIGH, LOW } },
  { LEVEL_OFF,  {HIGH,  HIGH, HIGH, HIGH, HIGH} },
};
static Level g_currentLevel = LEVEL_OFF;

static inline void applyLevel(Level lv) {
  for (size_t t = 0; t < sizeof(kLevelTable) / sizeof(kLevelTable[0]); ++t) {
    if (kLevelTable[t].level != lv) continue;
    for (int i = 0; i < kLevelPinCount; ++i) digitalWrite(kLevelPins[i], kLevelTable[t].pinState[i]);
    g_currentLevel = lv;
    return;
  }
  // fallback
  for (int i = 0; i < kLevelPinCount; ++i) digitalWrite(kLevelPins[i], HIGH);
  digitalWrite(kLevelPins[0], LOW);
  g_currentLevel = LEVEL_OFF;
}

// =========================
// Sequences
// =========================
const Step seqA[] = {
  {100,97,95,50,50,LEVEL_KEEP},{85,87,95,70,0,LEVEL_LOW},{85,87,95,1,50,LEVEL_MID},
  {85,87,95,1,50,LEVEL_HIGH},{100,97,95,70,500,LEVEL_FULL},{85,87,95,70,0,LEVEL_LOW},
  {85,87,95,1,50,LEVEL_MID},{85,87,95,1,50,LEVEL_HIGH},{97,96,95,80,500,LEVEL_FULL},
  {88,91,95,120,700,LEVEL_HIGH},{88,91,95,1,50,LEVEL_MID},{88,91,95,1,50,LEVEL_LOW},
  {80,87,95,50,50,LEVEL_OFF}
};
const Step seqB[] = {
  {112,97,95,10,700,LEVEL_FULL},{90,97,95,1,70,LEVEL_FULL},{112,97,95,1,70,LEVEL_FULL},
  {90,97,95,1,70,LEVEL_FULL},{112,97,95,1,70,LEVEL_FULL}
};
const Step seqC[] = {
  {112,97,95,60,100,LEVEL_FULL},{112,90,95,60,100,LEVEL_FULL},{112,97,95,60,500,LEVEL_FULL},
  {104,97,95,60,500,LEVEL_HIGH},{104,97,95,50,100,LEVEL_MID},{104,97,95,1,1000,LEVEL_LOW}
};
const Step seqD[] = {
  {104,97,95,60,100,LEVEL_LOW},{104,90,95,60,100,LEVEL_LOW},{104,97,95,60,500,LEVEL_LOW},
  {112,97,95,40,500,LEVEL_MID},{112,97,95,50,100,LEVEL_HIGH},{112,97,95,1,100,LEVEL_FULL}
};
const Step seqE[] = {
  {102,97,95,15,100,LEVEL_OFF},{102,97,95,1,100,LEVEL_LOW},{102,97,95,1,100,LEVEL_MID},
  {102,97,95,1,100,LEVEL_HIGH},{102,97,95,1,100,LEVEL_FULL},{102,97,95,1,100,LEVEL_HIGH},
  {102,97,95,1,100,LEVEL_MID},{102,97,95,1,100,LEVEL_LOW},{102,97,95,1,100,LEVEL_MID},
  {102,97,95,1,100,LEVEL_HIGH},{102,97,95,1,100,LEVEL_FULL},{102,97,95,1,100,LEVEL_HIGH},
  {102,97,95,1,100,LEVEL_LOW},{102,97,95,1,100,LEVEL_MID},{102,97,95,1,100,LEVEL_HIGH},
  {102,97,95,1,100,LEVEL_FULL},{102,97,95,1,100,LEVEL_HIGH},{102,97,95,1,100,LEVEL_MID},
  {102,97,95,1,100,LEVEL_LOW},{102,97,95,1,100,LEVEL_MID},{102,97,95,1,100,LEVEL_HIGH},
  {102,97,95,1,100,LEVEL_FULL},{102,97,95,1,100,LEVEL_HIGH},{102,97,100,15,1,LEVEL_MID},
  {102,97,90,15,1,LEVEL_LOW},{102,97,100,15,1,LEVEL_LOW},{102,97,90,15,1,LEVEL_LOW},
  {102,97,95,15,70,LEVEL_LOW},{90,97,95,15,70,LEVEL_LOW},{102,97,95,15,70,LEVEL_LOW}
};
const Step seqF[] = {
  {80,87,95,100,500,LEVEL_KEEP},{80,87,100,100,50,LEVEL_KEEP},{80,87,90,50,50,LEVEL_KEEP},
  {80,87,100,50,50,LEVEL_KEEP},{80,87,90,50,50,LEVEL_KEEP},{80,87,95,90,400,LEVEL_KEEP},
  {80,87,95,90,50,LEVEL_OFF}
};
const Step seqG[] = {
  {112,97,95,50,100,LEVEL_LOW},{90,97,95,5,70,LEVEL_LOW},{112,97,95,5,70,LEVEL_FULL},
  {112,97,85,50,100,LEVEL_FULL},{112,90,85,60,400,LEVEL_FULL},{112,97,85,60,150,LEVEL_FULL},
  {112,97,95,55,1000,LEVEL_FULL}
};
const Step seqH[] = {
  {90,97,95,1,70,LEVEL_KEEP},{112,97,95,1,70,LEVEL_KEEP}
};
const Step seqI[] = {
  {90,97,95,2,70,LEVEL_KEEP},{104,97,95,2,70,LEVEL_KEEP}
};

const Sequence SEQA = { seqA, (int)(sizeof(seqA) / sizeof(seqA[0])) };
const Sequence SEQB = { seqB, (int)(sizeof(seqB) / sizeof(seqB[0])) };
const Sequence SEQC = { seqC, (int)(sizeof(seqC) / sizeof(seqC[0])) };
const Sequence SEQD = { seqD, (int)(sizeof(seqD) / sizeof(seqD[0])) };
const Sequence SEQE = { seqE, (int)(sizeof(seqE) / sizeof(seqE[0])) };
const Sequence SEQF = { seqF, (int)(sizeof(seqF) / sizeof(seqF[0])) };
const Sequence SEQG = { seqG, (int)(sizeof(seqG) / sizeof(seqG[0])) };
const Sequence SEQH = { seqH, (int)(sizeof(seqH) / sizeof(seqH[0])) };
const Sequence SEQI = { seqI, (int)(sizeof(seqI) / sizeof(seqI[0])) };

// =========================
// Runtime state
// =========================
const Sequence* activeSeq = nullptr;
int activeSeqId = -1;
int idx = 0;
unsigned long holdStartMs = 0;
bool holding = false;
bool running = false;
bool seqActive[9] = { false };

unsigned long lastInteractionMs = 0;
const unsigned long IDLE_TIMEOUT_MS = 60000UL;

const unsigned long DETECT_DEBOUNCE_MS = 800;
unsigned long lastDetectMs = 0;

int lastCompletedSeqId = -1;
unsigned long lastCompletedMs = 0;

// SEQH/SEQI を除く最後の完了時刻（SEQA 自動起動判定用）
unsigned long lastNonBlinkCompletedMs = 0;

// SEQH / SEQI periodic timers
unsigned long lastBlinkHMs = 0;
unsigned long lastBlinkIMs = 0;
const unsigned long BLINK_INTERVAL_MS = 15000UL; // 15s

// SEQA auto after last non-blink (180s)
const unsigned long AUTO_AFTER_LAST_MS = 180000UL;

static const char* kLabels[] = {"wake_up","good_night","brightly","darkly","clap","blow"};
static const int kNumLabels = 6;
static float labelThresholds[kNumLabels] = {0.50f,0.50f,0.50f,0.50f,0.50f,0.50f};

// spectrogram buffers
static const int frames = 40;
static const int fft_samples = 96;
static float spc_data[frames * fft_samples];
static float hist[frames];

static const uint32_t buffering_time = BUFFERING_TIME_MS;
static const uint32_t buffer_size = BUFFER_SIZE_BYTES;

static char buff[BUFFER_SIZE_BYTES];
static float pDstFG[FFT_LEN];
static float pDstBG[FFT_LEN];
static float pDst[FFT_LEN / 2];

// =========================
// Helpers: startStep, getSequenceById, startSequence, stopSequence
// =========================
void startStep(int i) {
  const Step& st = activeSeq->steps[i];
  Eyelid.setTarget(st.eyelidDeg, st.stepDelayMs);
  Pitch.setTarget(st.pitchDeg, st.stepDelayMs);
  Yaw.setTarget(st.yawDeg, st.stepDelayMs);
  if (st.level != LEVEL_KEEP) applyLevel(st.level);
  holding = false;
}

const Sequence* getSequenceById(int id) {
  switch (id) {
    case 0: return &SEQA;
    case 1: return &SEQB;
    case 2: return &SEQC;
    case 3: return &SEQD;
    case 4: return &SEQE;
    case 5: return &SEQF;
    case 6: return &SEQG;
    case 7: return &SEQH;
    case 8: return &SEQI;
    default: return nullptr;
  }
}

void startSequence(const Sequence* seq, int seqId) {
  if (running) return;

  // block rules (original mapping)
  bool blocked = false;
  switch (lastCompletedSeqId) {
    case 0: if (seqId==0||seqId==2||seqId==3||seqId==5||seqId==7||seqId==8) blocked = true; break;
    case 1: if (seqId==1||seqId==3||seqId==6||seqId==8) blocked = true; break;
    case 2: if (seqId==2||seqId==6||seqId==7) blocked = true; break;
    case 3: if (seqId==3||seqId==6||seqId==8) blocked = true; break;
    case 4: if (seqId==2||seqId==6||seqId==7) blocked = true; break;
    case 5: if (seqId==0||seqId==2||seqId==3||seqId==5||seqId==7||seqId==8) blocked = true; break;
    case 6: if (seqId==1||seqId==3||seqId==6||seqId==8) blocked = true; break;
    case 7: if (seqId==1||seqId==3||seqId==6||seqId==8) blocked = true; break;
    case 8: if (seqId==1||seqId==2||seqId==6||seqId==7) blocked = true; break;
    default: break;
  }
  if (blocked) return;

  activeSeq = seq;
  activeSeqId = seqId;
  idx = 0;
  running = true;
  if (seqId >= 0 && seqId < 9) seqActive[seqId] = true;
  startStep(idx);
  Serial.print("sequence started id=");
  Serial.println(seqId);
  lastInteractionMs = millis();
}

void stopSequence() {
  running = false;
  activeSeq = nullptr;
  holding = false;
  if (activeSeqId >= 0 && activeSeqId < 9) seqActive[activeSeqId] = false;
  activeSeqId = -1;
  for (int i = 0; i < 9; ++i) seqActive[i] = false;
  applyLevel(LEVEL_OFF);
  Serial.println("sequence stopped");
  lastInteractionMs = millis();
}

// =========================
// setup
// =========================
void setup() {
  for (int i = 0; i < kLevelPinCount; ++i) pinMode(kLevelPins[i], OUTPUT);
  // apply LEVEL_FULL at startup
  for (size_t t = 0; t < sizeof(kLevelTable) / sizeof(kLevelTable[0]); ++t) {
    if (kLevelTable[t].level != LEVEL_FULL) continue;
    for (int i = 0; i < kLevelPinCount; ++i) digitalWrite(kLevelPins[i], kLevelTable[t].pinState[i]);
    g_currentLevel = LEVEL_FULL;
    break;
  }

  Eyelid.attach(3);
  Pitch.attach(6);
  Yaw.attach(5);

  Serial.begin(115200);

  unsigned long sdStart = millis();
  const unsigned long SD_TIMEOUT_MS = 10000UL;
  while (!SD.begin()) {
    if (millis() - sdStart > SD_TIMEOUT_MS) {
      Serial.println("SD init timeout");
      delay(1000);
      sdStart = millis();
    }
  }

  File nnbfile = SD.open(NNB_FILE);
  if (!nnbfile) { Serial.println("nnb not found"); while (1) delay(1000); }
  int ret = dnnrt.begin(nnbfile);
  nnbfile.close();
  if (ret < 0) { Serial.println("DNN init error"); while (1) delay(1000); }

  FFT.begin(WindowHamming, AS_CHANNEL_STEREO, (FFT_LEN / 2));

  theAudio->begin();
  theAudio->setRecorderMode(AS_SETRECDR_STS_INPUTDEVICE_MIC);
  int err = theAudio->initRecorder(AS_CODECTYPE_PCM, "/mnt/sd0/BIN", AS_SAMPLINGRATE_16000, AS_CHANNEL_STEREO);
  if (err != AUDIOLIB_ECODE_OK) { Serial.println("Recorder init error"); while (1) delay(1000); }
  theAudio->startRecorder();

  memset(spc_data, 0, sizeof(spc_data));
  memset(hist, 0, sizeof(hist));

  lastInteractionMs = millis();
  lastBlinkHMs = millis();
  lastBlinkIMs = millis();
  lastNonBlinkCompletedMs = 0;
}

// =========================
// loop
// =========================
void loop() {
  unsigned long now = millis();

  // minimal serial commands
  while (Serial.available()) {
    char c = Serial.read();
    if (c == '\r' || c == '\n') continue;
    lastInteractionMs = now;
    if (c == 's') { stopSequence(); continue; }
    if (c == 'r') {
      if (activeSeqId >= 0 && activeSeqId < 9) {
        const Sequence* seq = getSequenceById(activeSeqId);
        if (seq) startSequence(seq, activeSeqId);
      }
      continue;
    }
    if (!running) {
      if      (c == 'a') startSequence(&SEQA, 0);
      else if (c == 'b') startSequence(&SEQB, 1);
      else if (c == 'c') startSequence(&SEQC, 2);
      else if (c == 'd') startSequence(&SEQD, 3);
      else if (c == 'e') startSequence(&SEQE, 4);
      else if (c == 'f') startSequence(&SEQF, 5);
      else if (c == 'g') startSequence(&SEQG, 6);
      else if (c == 'h') startSequence(&SEQH, 7);
      else if (c == 'i') startSequence(&SEQI, 8);
    }
  }

  // SEQA auto-start: 45s after last non-blink completed
  if (!running && lastNonBlinkCompletedMs != 0) {
    if (now - lastNonBlinkCompletedMs >= AUTO_AFTER_LAST_MS) {
      startSequence(&SEQA, 0);
    }
  }

  // SEQH periodic auto-run (17s), skip if lastCompletedSeqId == 4 (blow)
  if (!running && (now - lastBlinkHMs >= BLINK_INTERVAL_MS) && lastCompletedSeqId != 4) {
    startSequence(&SEQH, 7);
    if (running && activeSeqId == 7) lastBlinkHMs = now;
  }

  // SEQI periodic auto-run (17s), skip if lastCompletedSeqId == 4 (blow)
  if (!running && (now - lastBlinkIMs >= BLINK_INTERVAL_MS) && lastCompletedSeqId != 4) {
    startSequence(&SEQI, 8);
    if (running && activeSeqId == 8) lastBlinkIMs = now;
  }

  // servo updates
  Eyelid.update(now);
  Pitch.update(now);
  Yaw.update(now);

  if (running) {
    if (Eyelid.moving() || Pitch.moving() || Yaw.moving()) {
      // wait for servos
    } else {
      if (!holding) { holding = true; holdStartMs = now; }
      if ((now - holdStartMs) >= (activeSeq ? activeSeq->steps[idx].holdMs : 0)) {
        if (activeSeq) {
          idx++;
          if (idx >= activeSeq->count) {
            if (activeSeqId >= 0 && activeSeqId < 9) seqActive[activeSeqId] = false;
            lastCompletedSeqId = activeSeqId;
            lastCompletedMs = now;
            // update lastNonBlinkCompletedMs only if not blink sequences (7 or 8)
            if (lastCompletedSeqId != 7 && lastCompletedSeqId != 8) {
              lastNonBlinkCompletedMs = now;
            }
            running = false;
            activeSeq = nullptr;
            activeSeqId = -1;
            Serial.print("sequence finished id=");
            Serial.println(lastCompletedSeqId);
            lastInteractionMs = now;
          } else {
            startStep(idx);
          }
        }
      }
    }
  }

  // ====== audio frame read ======
  uint32_t read_size = 0;
  int ret = theAudio->readFrames(buff, buffer_size, &read_size);
  if (ret != AUDIOLIB_ECODE_OK && ret != AUDIOLIB_ECODE_INSUFFICIENT_BUFFER_AREA) {
    while (1) delay(1000);
  }
  if (read_size < buffer_size) {
    delay(buffering_time);
    return;
  }

  // ====== FFT ======
  FFT.put((q15_t*)buff, FFT_LEN);
  FFT.get(pDstFG, 0);
  FFT.get(pDstBG, 1);

  // MIC-A/B diff + clamp
  const float alpha = 0.8f;
  for (int f = 0; f < FFT_LEN / 2; ++f) {
    float v = pDstFG[f] - alpha * pDstBG[f];
    pDst[f] = (v < 0.0f) ? 0.0f : v;
  }

  // smoothing (moving average)
  const int array_size = 4;
  static float pArray[array_size][FFT_LEN / 2];
  static int g_counter = 0;
  if (g_counter == array_size) g_counter = 0;
  for (int i = 0; i < FFT_LEN / 2; ++i) {
    pArray[g_counter][i] = pDst[i];
    float sum = 0;
    for (int j = 0; j < array_size; ++j) sum += pArray[j][i];
    pDst[i] = sum / array_size;
  }
  ++g_counter;

  // spectrogram shift
  memmove(spc_data, spc_data + fft_samples, (frames - 1) * fft_samples * sizeof(float));
  memmove(hist, hist + 1, (frames - 1) * sizeof(float));

  float sound_power_nc = 0.0f;
  for (int f = 0; f < FFT_LEN / 2; ++f) sound_power_nc += pDst[f];

  hist[frames - 1] = sound_power_nc;
  float* sp_last = spc_data + (frames - 1) * fft_samples;
  memcpy(sp_last, pDst, fft_samples * sizeof(float));

  // VAD (pre/target/post = 6/28/6)
  const float sound_th = 70.0f;
  const float silent_th = 10.0f;
  float pre_area = 0.0f, target_area = 0.0f, post_area = 0.0f;
  for (int t = 0; t < frames; ++t) {
    if (t < 6) pre_area += hist[t];
    else if (t < 6 + 28) target_area += hist[t];
    else post_area += hist[t];
  }

  if (pre_area < silent_th && target_area >= sound_th && post_area < silent_th) {
    unsigned long now3 = millis();
    if (now3 - lastDetectMs < DETECT_DEBOUNCE_MS) {
      // ignore
    } else {
      lastDetectMs = now3;
      memset(hist, 0, sizeof(hist));

      // prepare DNN input
      float spmax = -FLT_MAX, spmin = FLT_MAX;
      for (int n = 0; n < frames * fft_samples; ++n) {
        float v = spc_data[n];
        if (v > spmax) spmax = v;
        if (v < spmin) spmin = v;
      }
      float denom = spmax - spmin;
      if (denom < 1e-9f) denom = 1e-9f;

      DNNVariable input(28 * 48);
      float* din = input.data();
      const int t_begin = 6;
      const int t_end = 6 + 28;
      int bf = (fft_samples / 2) - 1;
      for (int f = 0; f < fft_samples; f += 2) {
        int bt = 0;
        for (int t = t_begin; t < t_end; ++t) {
          float v0 = (spc_data[fft_samples * t + f] - spmin) / denom;
          float v1 = (spc_data[fft_samples * t + f + 1] - spmin) / denom;
          float v01 = 0.5f * (v0 + v1);
          if (v01 < 0.f) v01 = 0.f;
          if (v01 > 1.f) v01 = 1.f;
          din[28 * bf + bt] = v01;
          ++bt;
        }
        --bf;
      }

      // inference
      dnnrt.inputVariable(input, 0);
      dnnrt.forward();
      DNNVariable output = dnnrt.outputVariable(0);

      int index = -1;
      float value = -1.0f;
      int out_size = output.size();
      float* out_data = output.data();
      if (out_size > 0) {
        index = 0;
        value = out_data[0];
        for (int i = 1; i < out_size; ++i) {
          if (out_data[i] > value) { value = out_data[i]; index = i; }
        }
        if (index < 0 || index >= kNumLabels) index = -1;
        else if (value < labelThresholds[index]) index = -1;
      }

      lastInteractionMs = now3;

      // minimal serial: detection result and sequence mapping
      if (index >= 0 && index < kNumLabels) {
        Serial.print(kLabels[index]);
        Serial.print(" : ");
        Serial.println(value, 6);
        switch (index) {
          case 0: startSequence(&SEQG, 6); break;
          case 1: startSequence(&SEQF, 5); break;
          case 2: startSequence(&SEQD, 3); break;
          case 3: startSequence(&SEQC, 2); break;
          case 4: startSequence(&SEQB, 1); break;
          case 5: startSequence(&SEQE, 4); break;
          default: break;
        }
      } else {
        Serial.print("class#");
        Serial.print(index);
        Serial.print(" : ");
        Serial.println(value, 6);
      }
    }
  }
}

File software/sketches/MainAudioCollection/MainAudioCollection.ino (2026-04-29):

/**
 * LIGHTONY ROBOT - Audio Data Collection Utility
 * * This sketch is used to collect voice data for training the neural network 
 * model used in the LIGHTONY robot.
 * * Acknowledgments:
 * This utility is based on the "MainAudioCollection.ino" sample from:
 * - Book: "SPRESENSEではじめるローパワーエッジAI" by Yoshinori Oota
 * - Repository: https://github.com/TE-YoshinoriOota/Spresense-LowPower-EdgeAI
 * * Specialized for capturing voice commands to improve LIGHTONY's 
 * recognition accuracy.
 */

#ifdef SUBCORE
#error "Core selection is wrong!!"
#endif

#include <Audio.h>
#include <FFT.h>

#define FFT_LEN 512

// ステレオ、512サンプルでFFTを初期化
FFTClass<AS_CHANNEL_STEREO, FFT_LEN> FFT;

AudioClass* theAudio = AudioClass::getInstance();

#include <MP.h>
#include <MPMutex.h>          // サブコア間の同期ライブラリ
MPMutex mutex(MP_MUTEX_ID0);
const int subcore = 1;        // サブコアの番号

#include <SDHCI.h>
SDClass SD;
File myFile;

#include <float.h> // FLT_MAX, FLT_MIN
#include <BmpImage.h>
BmpImage bmp;

// ===================== パラメータ定義 =====================
static const int frames         = 40;  // 時間方向（内部保持列数） 6+28+6
static const int fft_samples    = 96;  // 周波数方向（使用bin数 0..約3kHz想定）
static const int pre_frames     = 6;   // 無音プリ
static const int target_frames  = 28;  // 発話区間（抽出・保存対象）
static const int post_frames    = 6;   // 無音ポスト

static const int time_cols      = target_frames; // BMP横幅 28（=target）
static const int freq_rows      = 48;            // BMP縦幅 96→2bin平均で48

static const float alpha = 0.8f; // Rch抑圧係数（環境音抑圧）
static const float sound_th  = 70.f; // 発話しきい値（総エネルギー）
static const float silent_th = 10.f; // 無音しきい値

// ===================== 平滑化（4フレーム移動平均） =====================
void averageSmooth(float* dst) {
  const int array_size = 4;
  static float pArray[array_size][FFT_LEN/2];
  static int g_counter = 0;
  if (g_counter == array_size) g_counter = 0;
  for (int i = 0; i < FFT_LEN/2; ++i) {
    pArray[g_counter][i] = dst[i];
    float sum = 0;
    for (int j = 0; j < array_size; ++j) {
      sum += pArray[j][i];
    }
    dst[i] = sum / array_size;
  }
  ++g_counter;
}

void setup() {
  Serial.begin(115200);

  pinMode(LED_BUILTIN, OUTPUT);
  digitalWrite(LED_BUILTIN, LOW);

  while (!SD.begin()) { Serial.println("insert SD card"); }

  FFT.begin(WindowHamming, AS_CHANNEL_STEREO, (FFT_LEN/2));

  Serial.println("Init Audio Recorder");
  theAudio->begin();

  theAudio->setRecorderMode(AS_SETRECDR_STS_INPUTDEVICE_MIC);

  int err = theAudio->initRecorder(AS_CODECTYPE_PCM,
                                   "/mnt/sd0/BIN",
                                   AS_SAMPLINGRATE_16000,
                                   AS_CHANNEL_STEREO);
  if (err != AUDIOLIB_ECODE_OK) {
    Serial.println("Recorder initialize error");
    while (1);
  }

  Serial.println("Start Recorder");
  theAudio->startRecorder(); // 録音開始

  MP.begin(subcore); // サブコア開始
}

void loop() {
  static const uint32_t buffering_time =
      FFT_LEN * 1000 / AS_SAMPLINGRATE_16000; // ≒ 32ms
  static const uint32_t buffer_size =
      FFT_LEN * sizeof(int16_t) * AS_CHANNEL_STEREO; 

  static char  buff[buffer_size]; 
  static float pDstFG[FFT_LEN];   
  static float pDstBG[FFT_LEN];   
  static float pDst[FFT_LEN/2];   

  static float spc_data[frames * fft_samples];
  static float hist[frames];

  uint32_t read_size;
  int ret;

  ret = theAudio->readFrames(buff, buffer_size, &read_size);
  if (ret != AUDIOLIB_ECODE_OK &&
      ret != AUDIOLIB_ECODE_INSUFFICIENT_BUFFER_AREA) {
    Serial.println(String("Error err = ") + String(ret));
    theAudio->stopRecorder();
    while (1);
  }
  if (read_size < buffer_size) {
    delay(buffering_time);
    return;
  }


  FFT.put((q15_t*)buff, FFT_LEN);
  FFT.get(pDstFG, 0);  // MIC-A
  FFT.get(pDstBG, 1);  // MIC-B


  for (int f = 0; f < FFT_LEN/2; ++f) {
    float v = pDstFG[f] - alpha * pDstBG[f];
    pDst[f] = v < 0.f ? 0.f : v;
  }
  averageSmooth(pDst);


  for (int t = 1; t < frames; ++t) {
    float* dst = spc_data + (t-1) * fft_samples;
    float* src = spc_data +  t    * fft_samples;
    memcpy(dst, src, fft_samples * sizeof(float));
    hist[t-1] = hist[t];
  }


  float sound_power_nc = 0.f;
  for (int f = 0; f < FFT_LEN/2; ++f) sound_power_nc += pDst[f];
  hist[frames-1] = sound_power_nc;

  float* sp_last = spc_data + (frames-1) * fft_samples;
  memcpy(sp_last, pDst, fft_samples * sizeof(float));


  float pre_area = 0.f, target_area = 0.f, post_area = 0.f;
  for (int t = 0; t < frames; ++t) {
    if (t < pre_frames)                        pre_area    += hist[t];
    else if (t < pre_frames + target_frames)   target_area += hist[t];
    else                                       post_area   += hist[t];
  }

  if (pre_area < silent_th && target_area >= sound_th && post_area < silent_th) {

    memset(hist, 0, sizeof(hist));

    uint8_t bmp_data[time_cols * freq_rows];
    
    float spmax = FLT_MIN, spmin = FLT_MAX;
    for (int n = 0; n < frames * fft_samples; ++n) {
      float v = spc_data[n];
      if (v > spmax) spmax = v;
      if (v < spmin) spmin = v;
    }
    float denom = spmax - spmin;
    if (denom < 1e-9f) denom = 1e-9f; 

    int row = freq_rows - 1; 
    for (int f = 0; f < fft_samples; f += 2) {
      int col = 0; 
      for (int t = pre_frames; t < pre_frames + target_frames; ++t) {
        float v0 = (spc_data[fft_samples * t + f    ] - spmin) / denom;
        float v1 = (spc_data[fft_samples * t + f + 1] - spmin) / denom;
        float v  = (v0 + v1) * 0.5f * 255.f;
        if (v < 0.f)   v = 0.f;
        if (v > 255.f) v = 255.f;
        // バッファは行優先：index = 幅 * 行 + 列
        bmp_data[time_cols * row + col] = (uint8_t)(v + 0.5f);
        ++col;
      }
      --row;
    }

    digitalWrite(LED_BUILTIN, HIGH);   
    theAudio->stopRecorder();

    bool saved = false;
    do {
      static int n = 0;
      char fname[32]; memset(fname, 0, sizeof(fname));
      sprintf(fname, "%03d.bmp", n++);
      if (SD.exists(fname)) SD.remove(fname);

      File myFile = SD.open(fname, FILE_WRITE);
      if (!myFile) {
        Serial.println("SD open failed");
        break;
      }

      bmp.begin(BmpImage::BMP_IMAGE_GRAY8,
                time_cols,      
                freq_rows,      
                bmp_data);

      size_t expect_min = 2200; 
      size_t written = myFile.write(bmp.getBmpBuff(), bmp.getBmpSize());
      myFile.close();
      bmp.end();

      Serial.print("bmp size: "); Serial.println(bmp.getBmpSize());
      Serial.print("written:  "); Serial.println(written);
      Serial.println(String("save image as ") + fname);

      if (written > expect_min) saved = true; else Serial.println("Warning: written size too small");
    } while (0);

    theAudio->startRecorder();
    digitalWrite(LED_BUILTIN, LOW);    
    if (!saved) { Serial.println("save failed"); }
  }
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

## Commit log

2026-04-29 Add software files
    [cache_index.csv, cache_info.csv, order.csv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]
2026-05-12 Add initial hardware files
    [arm-frame-lower.stl, arm-frame-upper.stl, arm-hand-left.stl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]
2026-05-12 Remove .xlsx files
    [control-board-bom.xlsx, electronics-bom.xlsx, mechanical-bom.xlsx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]
